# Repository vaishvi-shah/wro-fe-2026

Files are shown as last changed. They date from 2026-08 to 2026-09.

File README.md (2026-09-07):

# Hello! We are Team ElectroCute

<table align="center">
  <tr>
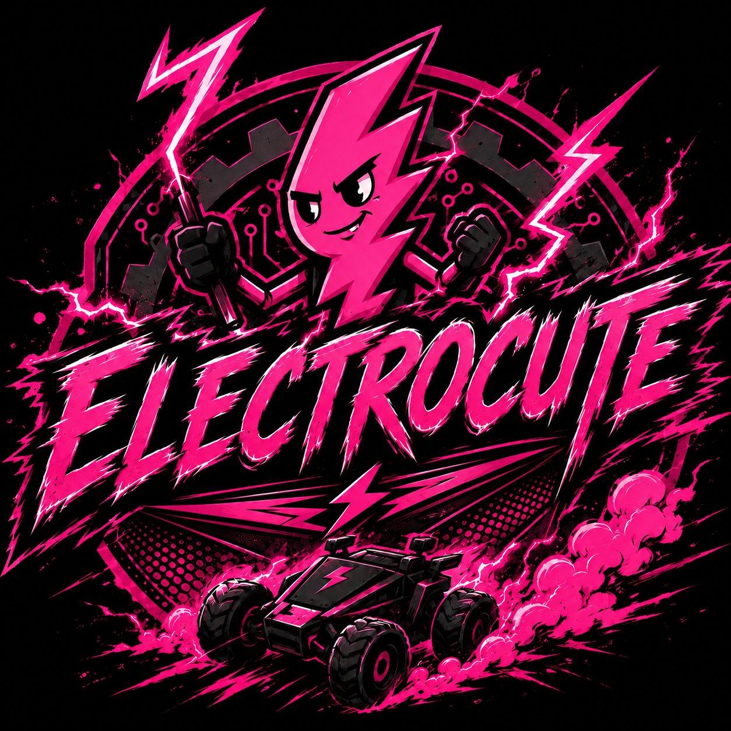
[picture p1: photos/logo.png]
    <td align="center"></td>
  </tr>
  <tr>
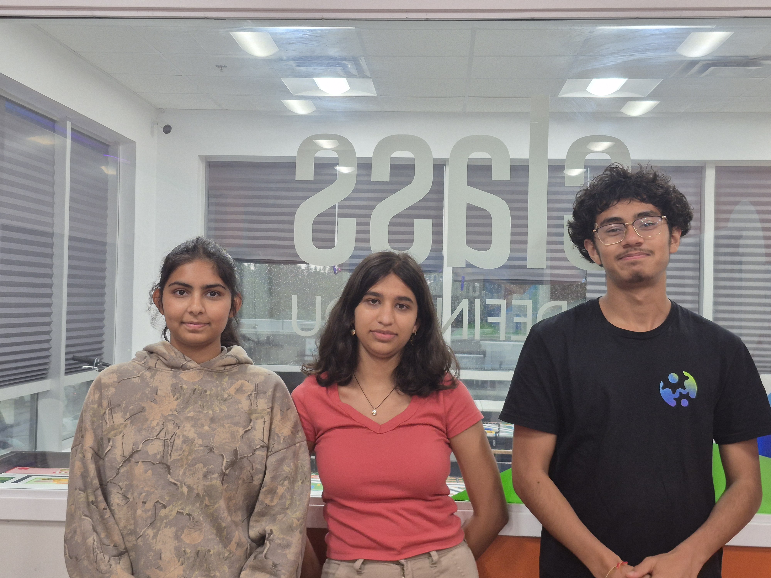
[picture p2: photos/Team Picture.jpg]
    <td align="center"></td>
  </tr>
</table>

We are a team of high school students from Whitby, Ontario, Canada participating in the **World Robot Olympiad (WRO) Future Engineers 2026** category.

<table align="center">
  <tr>
    <td align="center"><strong>Member</strong></td>
    <td align="center"><strong>Role</strong></td>
  </tr>
  <tr>
    <td align="center">Vaishvi Shah</td>
    <td align="center">Software &amp; Logic</td>
  </tr>
  <tr>
    <td align="center">Avani Devalankar</td>
    <td align="center">3D Design &amp; Hardware</td>
  </tr>
  <tr>
    <td align="center">Jaitra Bhatt</td>
    <td align="center">Documentation</td>
  </tr>
</table>

# Overview

The primary objective was to build an autonomous robot capable of navigating a closed course with obstacles and parallel parking itself at the end.

We chose this project because we wanted a challenging experience during high school where we could apply our Python skills while developing new skills in electronics, CAD, and 3D printing. We also drew inspiration from top teams that participated in WRO Future Engineers over the past two years by studying their [GitHub repositories](https://github.com/World-Robot-Olympiad-Association).

Our main objective was to create a dependable and effective system while showcasing our engineering, problem-solving, and teamwork skills. The project also gave us an opportunity to expand our knowledge and develop new skills throughout the process of building our robot.

We approached the development through several stages, beginning with idea generation and research, followed by designing, building, testing, and refining our system. We also kept thorough records of our work to make it easier to share information, track changes, and maintain a consistent workflow throughout the project.

### Summary Video

<a href="https://www.youtube.com/watch?v=VKRCWfLhV6I">
  Watch video
</a>

Click above to watch our video!

### Open Challenge Videos

https://github.com/user-attachments/assets/b752e2d7-2efb-4881-ae9d-5aae1f4fcaa4

### Obstacle Video

https://github.com/user-attachments/assets/9520dfca-cd9e-48ff-8d53-4761ecfdaf9c

## Table of Content

- [Overview](#overview)
  - [Summary Video](#summary-video)
  - [Open Challenge Videos](#open-challenge-videos)
  - [Obstacle Video](#obstacle-video)
  - [Meet The Robot](#meet-the-robot)
    - [Preliminary Work](#preliminary-work)
- [Introduction](#introduction)
- [Mobility & Mechanical Design](#mobility--mechanical-design)
  - [First Iteration - LEGO Chassis](#first-iteration--lego-chassis)
  - [Second Iteration - 3D-Printed Chassis](#second-iteration--3d-printed-chassis)
    - [Chassis Design](#chassis-design)
    - [Issues Identified](#issues-identified)
  - [Third Iteration - Physical Fit](#third-iteration--physical-fit)
    - [Chassis & Motor Fit](#chassis--motor-fit)
    - [Chassis & Weight Distribution](#chassis--weight-distribution)
    - [Mounting & Fastening](#mounting--fastening)
    - [Accessibility & Wiring](#accessibility--wiring)
    - [Battery Placement](#battery-placement)
    - [Rear Wheel Bearings](#rear-wheel-bearings)
    - [Screw Usage](#screw-usage)
- [Parts Selection & Reasoning](#parts-selection--reasoning)
  - [Drive System](#drive-system)
    - [Motor Selection](#motor-selection)
      - [Motor 1: JGA25-371 620 RPM DC Motor](#motor-1-jga25-371-620-rpm-dc-motor)
        - [Motor 1 Specifications](#motor-1-specifications)
      - [Motor 2: Lower-RPM JGA25-371 Variant](#motor-2-lower-rpm-jga25-371-variant)
    - [Motor Torque and Acceleration Calculations](#motor-torque-and-acceleration-calculations)
      - [Parameters](#parameters)
      - [Summary](#summary)
      - [Motor Final Decision](#motor-final-decision)
    - [Steering, Servo & Differential Design](#steering-servo--differential-design)
      - [WLToys 144001](#wltoys-144001)
      - [Ackermann Steering](#ackermann-steering)
      - [Servo: MG90S Servo](#servo-mg90s-servo)
        - [Servo Specifications](#servo-specifications)
  - [Power & Sensor Architecture](#power--sensor-architecture)
    - [Component Placement](#component-placement)
    - [Microcontroller Selection & Development](#microcontroller-selection--development)
      - [Iteration 1: micro:bit](#iteration-1-microbit)
      - [Raspberry Pi Pico 2 W](#raspberry-pi-pico-2-w)
    - [Raspberry Pi 5](#raspberry-pi-5)
      - [MPU6050](#mpu6050)
      - [BNO055](#bno055)
      - [IMU Comparison Table](#imu-comparison-table)
      - [IMU Final Decision](#imu-final-decision)
  - [Motor Driver Iterations](#motor-driver-iterations)
    - [Iteration 1 — DRV8871](#iteration-1--drv8871)
    - [Iteration 2 — L298N](#iteration-2--l298n)
    - [Motor Driver Comparison Table](#motor-driver-comparison-table)
    - [Motor Driver Final Decision](#motor-driver-final-decision)
  - [Camera: OV5647 Wide-Angle Camera](#camera-ov5647-wide-angle-camera)
  - [Parking: TOF Sensor vs. Motor Encoder](#parking-tof-sensor-vs-motor-encoder)
    - [Parking Sensor Comparison Table](#parking-sensor-comparison-table)
    - [Parking Sensor Final Decision](#parking-sensor-final-decision)
  - [Control, Display & Support System](#control-display--support-system)
- [Final Circuit Architecture](#final-circuit-architecture)
  - [Main Battery: 12V Li-ion Pack](#main-battery-12v-li-ion-pack)
  - [Steering Servo: MG90S vs. SG90](#steering-servo-mg90s-vs-sg90)
  - [Chassis Material: 3D-Printed PLA-CF](#chassis-material-3d-printed-pla-cf)
  - [Wheels: LEGO Wheels and Tires](#wheels-lego-wheels-and-tires)
- [Power System Architecture](#power-system-architecture)
  - [Two Board Architecture](#two-board-architecture)
    - [Why Two Boards?](#why-two-boards)
    - [Power Distribution](#power-distribution)
  - [Power Distribution Diagram: Nominal Values](#power-distribution-diagram-nominal-values)
  - [Nominal Current Draw for Each Part](#nominal-current-draw-for-each-part)
  - [Power Budget](#power-budget)
    - [5 V Power Requirement](#5-v-power-requirement)
    - [Motor Power](#motor-power)
    - [Total System Requirement](#total-system-requirement)
  - [Why This Matters](#why-this-matters)
- [Programming Logic](#programming-logic)
  - [Open Challenge Logic](#open-challenge-logic)
    - [1. Get Sensor Inputs](#1-get-sensor-inputs)
    - [2. Calculate Steering](#2-calculate-steering)
    - [3. Clamp Steering](#3-clamp-steering)
    - [4. Check for Bottom Lines](#4-check-for-bottom-lines)
  - [Obstacle Challenge Code](#obstacle-challenge-code)
    - [Iteration 1 — Initial Obstacle Avoidance](#iteration-1--initial-obstacle-avoidance)
      - [Iteration 1 Step 1: Detect an Obstacle](#iteration-1-step-1-detect-an-obstacle)
      - [Iteration 1 Step 2: Select the Obstacle to React To](#iteration-1-step-2-select-the-obstacle-to-react-to)
      - [Iteration 1 Step 3: Determine the Passing Side](#iteration-1-step-3-determine-the-passing-side)
      - [Iteration 1 Step 4: Find the Gap to Steer Through](#iteration-1-step-4-find-the-gap-to-steer-through)
      - [Iteration 1 Step 5: Steer Toward the Gap](#iteration-1-step-5-steer-toward-the-gap)
      - [Iteration 1 Step 6: Safety Check](#iteration-1-step-6-safety-check)
      - [Iteration 1 Step 7: Check if the Obstacle Was Cleared](#iteration-1-step-7-check-if-the-obstacle-was-cleared)
    - [Iteration 2 — Improved Obstacle Avoidance](#iteration-2--improved-obstacle-avoidance)
      - [Iteration 2 Step 1: Detect an Obstacle](#iteration-2-step-1-detect-an-obstacle)
      - [Iteration 2 Step 2: Select the Closest Obstacle](#iteration-2-step-2-select-the-closest-obstacle)
      - [Iteration 2 Step 3: Determine the Passing Side](#iteration-2-step-3-determine-the-passing-side)
      - [Iteration 2 Step 4: Improve the Gap Calculation](#iteration-2-step-4-improve-the-gap-calculation)
      - [Iteration 2 Step 5: Steer Toward the Gap](#iteration-2-step-5-steer-toward-the-gap)
      - [Iteration 2 Step 6: Safety Check — Obstacle Too Close](#iteration-2-step-6-safety-check--obstacle-too-close)
      - [Iteration 2 Step 7: Check if the Obstacle Is Cleared](#iteration-2-step-7-check-if-the-obstacle-is-cleared)
    - [Iteration Comparison](#iteration-comparison)
    - [Parking](#parking)
      - [`OUT_PARKING`](#out_parking)
      - [`IN_PARKING`](#in_parking)
    - [Running the Program](#running-the-program)
    - [Running the Program on Startup](#running-the-program-on-startup)
    - [CAD and Wiring Files](#cad-and-wiring-files)
  - [Step-by-Step Assembly Guide](#step-by-step-assembly-guide)
    - [1. Print the Chassis](#1-print-the-chassis)
    - [2. Assemble the Drivetrain](#2-assemble-the-drivetrain)
    - [3. Assemble the Steering](#3-assemble-the-steering)
    - [4. Mount Layer 1 Components](#4-mount-layer-1-components)
      - [Camera Position](#camera-position)
    - [5. Mount Layer 2 Components](#5-mount-layer-2-components)
    - [6. Wire the Power System](#6-wire-the-power-system)
      - [Wiring Recommendations](#wiring-recommendations)
    - [7. Wire Control Signals](#7-wire-control-signals)
    - [8. Attach the Front Bumper](#8-attach-the-front-bumper)
    - [9. Calibrate Before Every Run](#9-calibrate-before-every-run)
    - [10. Bench Test Before Full Track Runs](#10-bench-test-before-full-track-runs)
## Meet The Robot

<table align="center">
  <tr>
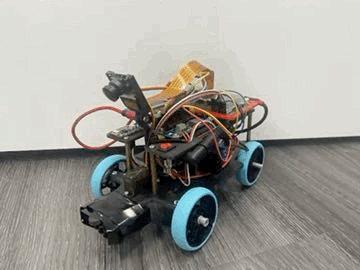
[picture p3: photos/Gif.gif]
    <td align="center"><strong>GIF</strong><br></td>
  </tr>
</table>
Meet Batmobile, our autonomous car designed and 3D-printed for WRO Future Engineers 2026. The brain of the robot is a Raspberry Pi 5, which processes the camera feed using OpenCV and handles navigation, obstacle detection, and sensor logic. A Raspberry Pi Pico communicates with the Pi through a USB serial connection and controls the DC motor and steering servo.

Batmobile uses a camera, IMU, and encoder sensor to navigate the field. The camera provides visual information for navigation and obstacle detection, the IMU helps maintain a straight heading and execute accurate turns, and the encoder sensor assists with precise parking. Together, these systems allow Batmobile to independently perceive its surroundings, make decisions, and navigate the competition field.

### Preliminary Work

We found the public WRO repositories especially useful when getting started. Being able to look at documentation from previous teams gave us a reference for how to approach the competition without having to figure everything out from scratch. We’ve tried to do the same with our documentation by making it practical and detailed enough that a future team can use it as a starting point for their own robot.

# Introduction

# Mobility & Mechanical Design

The chassis is built in a layered structure so that mounting space could be divided deliberately, with the first layer holding the heavier components and a second, elevated layer used to mount the electronics. This final version did not happen immediately; we went through many iterations to make it work.

## First Iteration  LEGO Chassis

**Starting Design**

Our first chassis was constructed using LEGO Technic pieces to create a basic structure for initial testing. A LEGO differential was incorporated into the drivetrain system to transfer power to the wheels while allowing them to rotate at different speeds during turns.

**Issues Identified**

During testing, we encountered several mechanical problems. The wheels frequently came off the chassis during movement and turning. The steering system also had a limited Ackermann steering angle, which made it difficult for the robot to perform tight turns. This was especially problematic during parking, where greater steering angles were needed to maneuver within the available space. Additionally, the differential would come off the axle during operation, affecting the reliability of the drivetrain.

<table align="center">
  <tr>
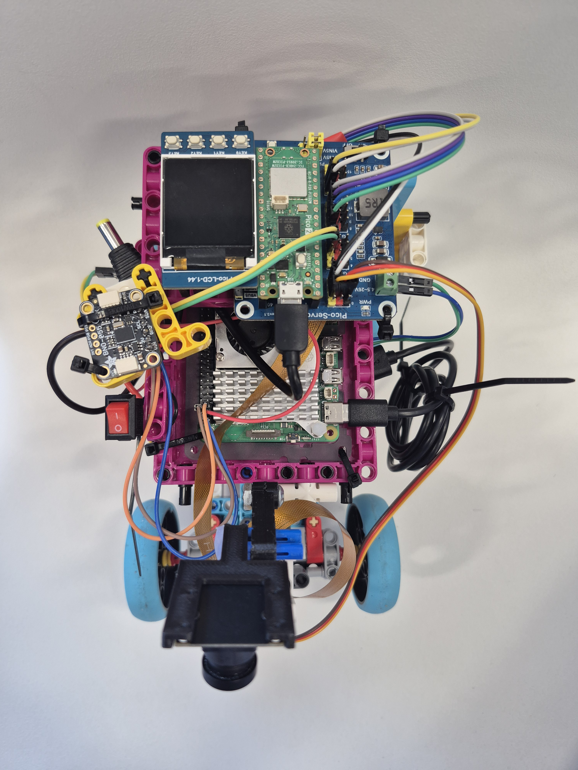
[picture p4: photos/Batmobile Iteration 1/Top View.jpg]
    <td></td>
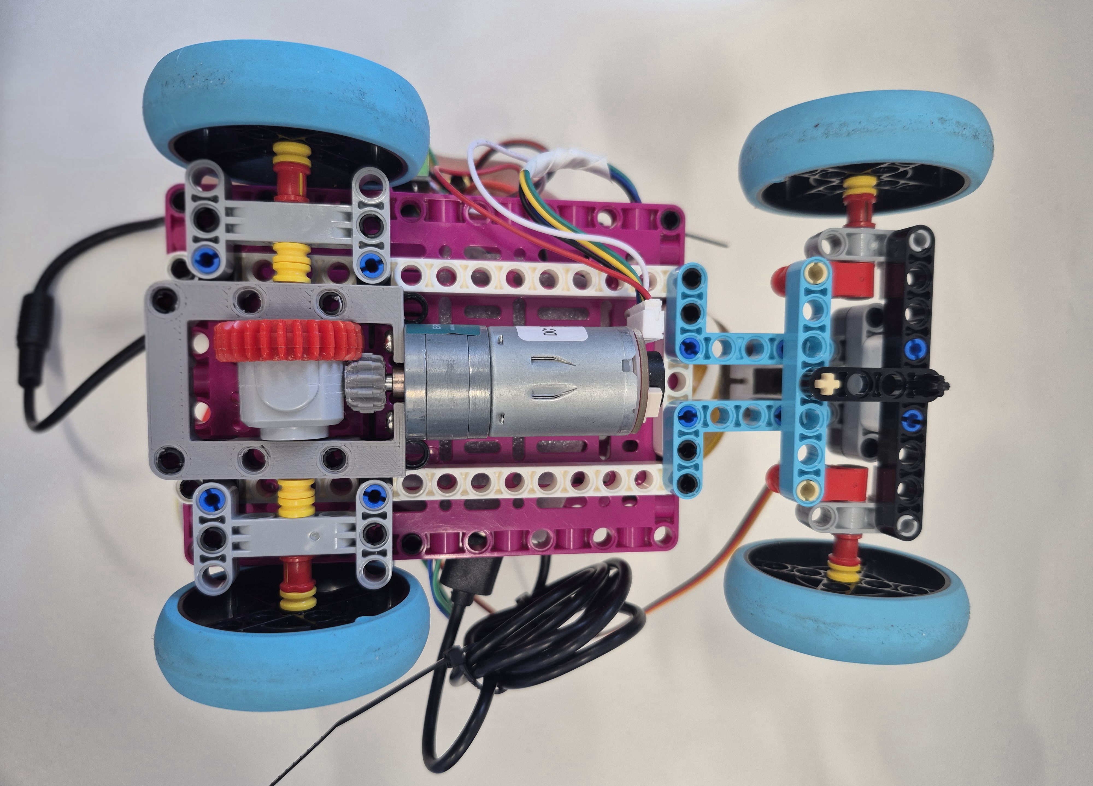
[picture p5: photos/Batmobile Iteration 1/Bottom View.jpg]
    <td></td>
  </tr>
  <tr>
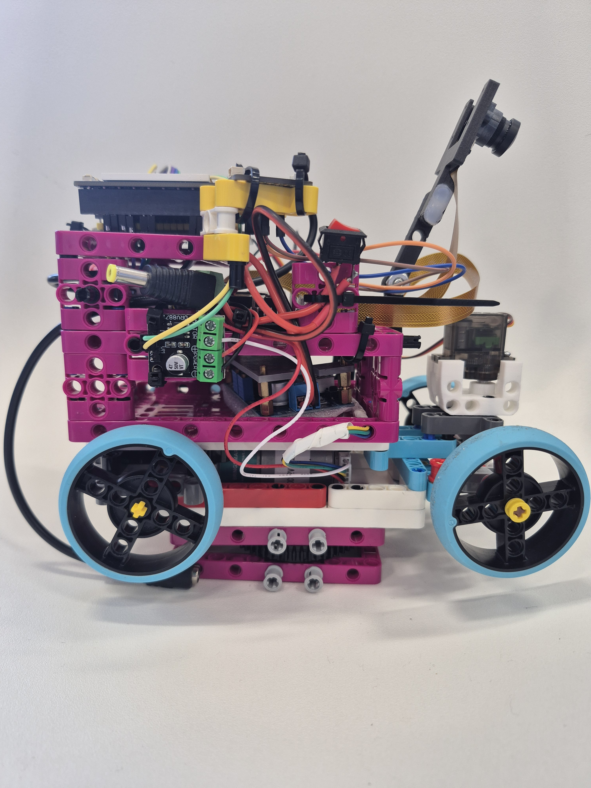
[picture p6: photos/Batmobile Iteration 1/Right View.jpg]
    <td></td>
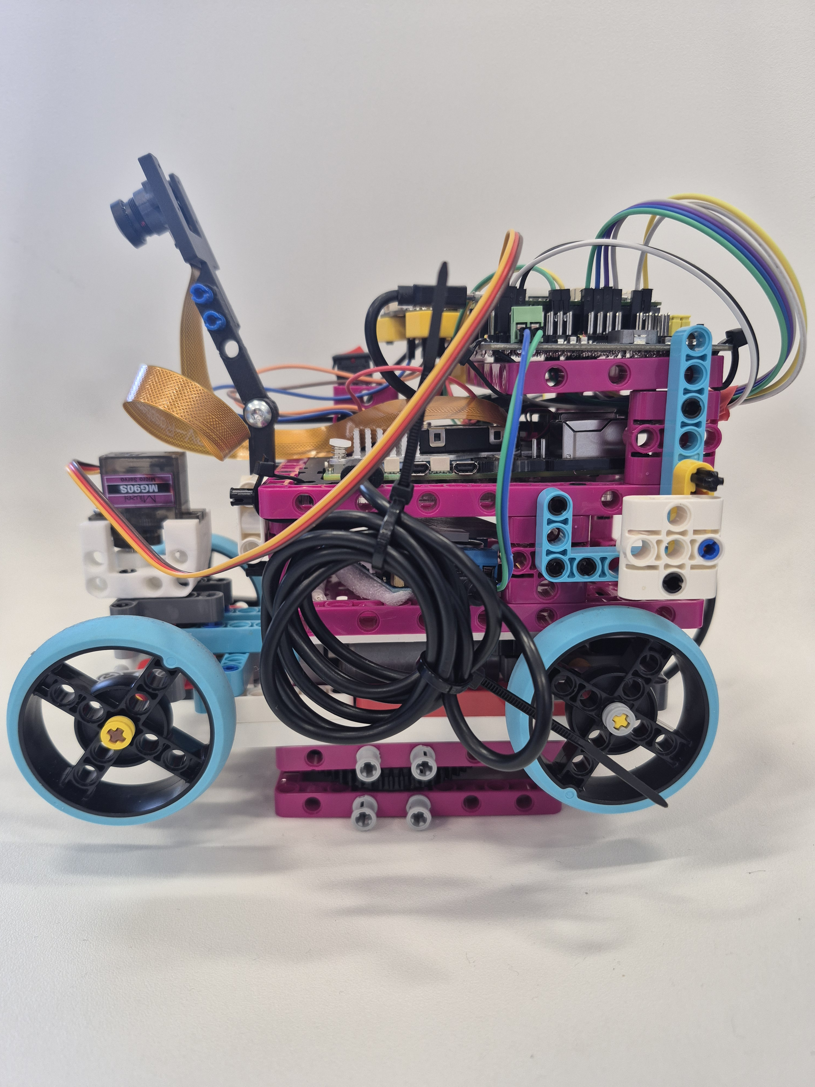
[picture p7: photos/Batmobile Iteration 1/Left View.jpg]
    <td></td>
  </tr>
</table>

## Second Iteration  3D-Printed Chassis

### Chassis Design

We replaced the original LEGO chassis with a custom 3D-printed chassis designed specifically around our robot’s components. The chassis was divided into two separate layers to organize the mechanical and electronic components:

- Layer 1: Battery, motor driver, servo, and Ackermann steering system.
- Layer 2: Raspberry Pi 5, Raspberry Pi Pico 2, and IMU.

This two-layer structure provided dedicated mounting areas, improved component organization, and made the overall system easier to assemble and maintain.

### Issues Identified

During testing, we found that placing the battery toward the rear of the chassis caused an uneven weight distribution. This shifted the centre of mass toward the rear, reducing the normal force acting on the front wheels.

With less weight on the front wheels, the available front-wheel traction decreased, particularly during faster movement and sharp turns. At higher speeds, the front wheels would lose traction and lift slightly, which reduced steering effectiveness and made the robot less stable and predictable while turning.

<table align="center">
  <tr>
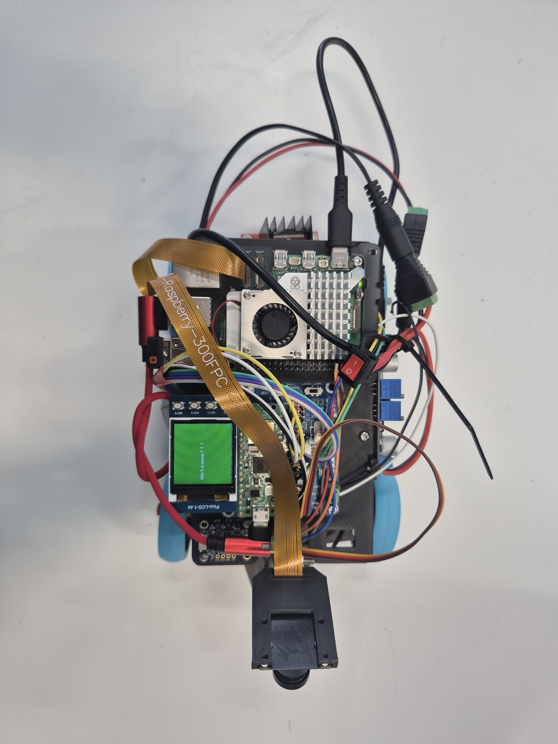
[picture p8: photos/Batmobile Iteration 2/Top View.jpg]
    <td></td>
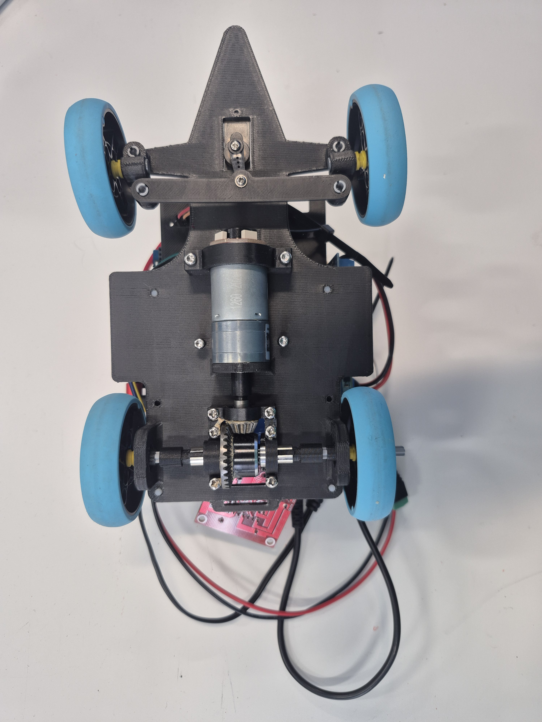
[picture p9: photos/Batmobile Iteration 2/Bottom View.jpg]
    <td></td>
  </tr>
  <tr>
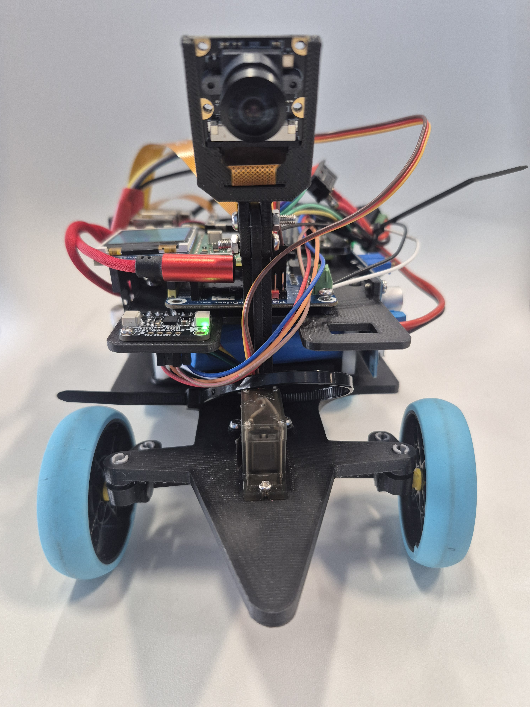
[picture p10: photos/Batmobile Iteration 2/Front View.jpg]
    <td></td>
    <td></td>
  </tr>
</table>

## Third Iteration  Physical Fit

<table align="center">
  <tr>
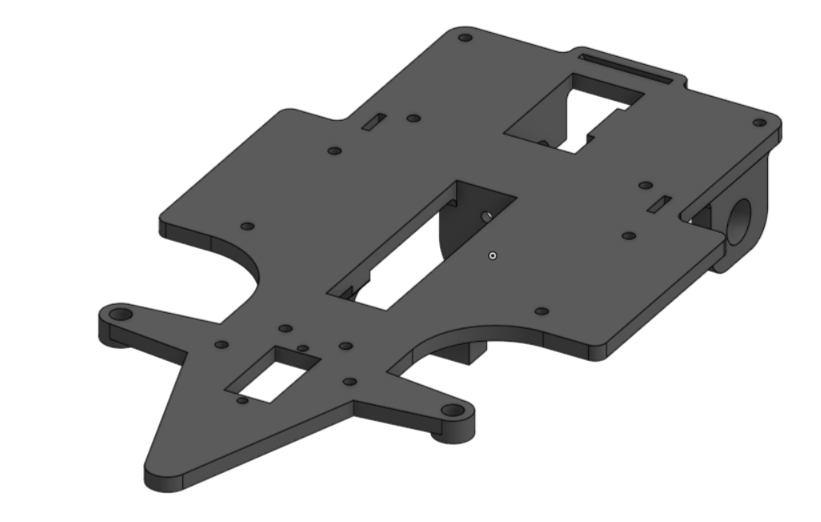
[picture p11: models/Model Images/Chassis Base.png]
    <td align="center"><strong>Chassis Base</strong><br></td>
  </tr>
</table>

### Chassis & Motor Fit

The chassis was extended after measuring the physical DC motor and discovering that it was longer than the original CAD model. An access hole was added to allow easier access to the motor mounting screws during assembly and maintenance. Finally, the motor clamp geometry was adjusted to improve the fit, including reducing the clamp diameter by 0.25 mm for a tighter connection.

### Chassis & Weight Distribution

The front of the chassis was extended to create more space for parking and make the robot easier to maneuver. We also moved the battery closer to the centre of the chassis to balance the weight more evenly and improve stability.

Additional space was made inside the chassis to fit the updated DC motor, which had different dimensions from the previous motor. We also replaced the previous motor driver with a new motor driver setup, so the layout of the internal components had to be adjusted to fit everything properly.

### Mounting & Fastening

The LEGO peg holes were increased by 0.1 mm after testing showed that the original holes were slightly too small. We also added dedicated mounting holes for the servo so it could be securely attached to the chassis.

Before finalizing the design, we test-fitted each clamp with its corresponding physical component. This helped us check that the dimensions were correct and catch any fitting issues before final assembly.

<table align="center">
  <tr>
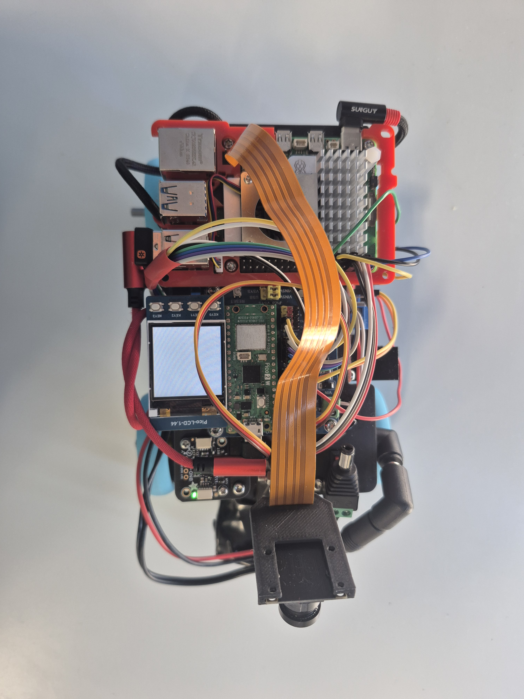
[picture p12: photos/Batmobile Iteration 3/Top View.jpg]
    <td></td>
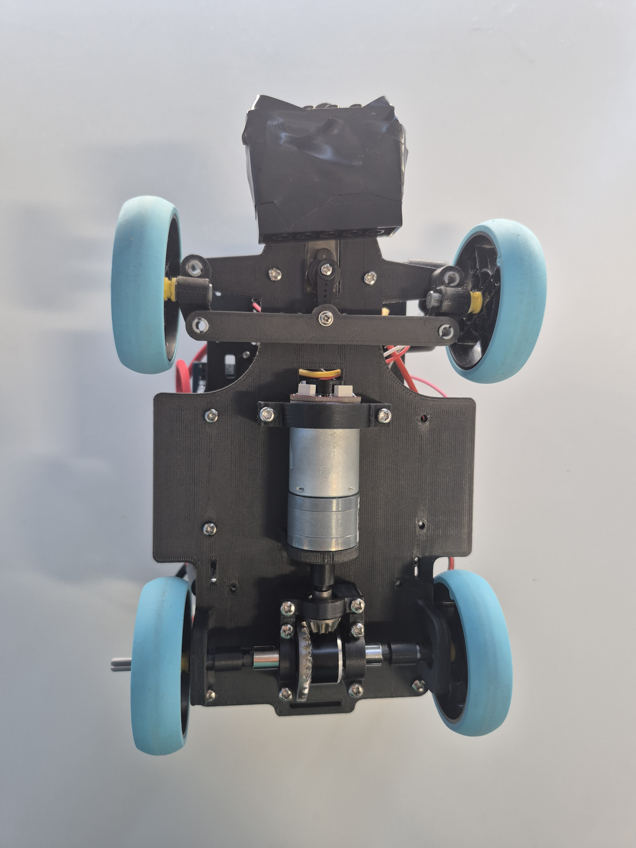
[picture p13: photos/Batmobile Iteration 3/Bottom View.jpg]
    <td></td>
  </tr>
  <tr>
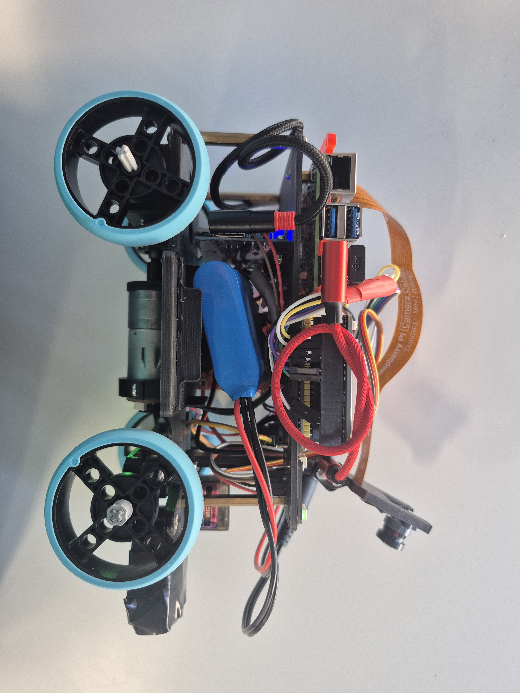
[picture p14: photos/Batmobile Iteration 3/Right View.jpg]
    <td></td>
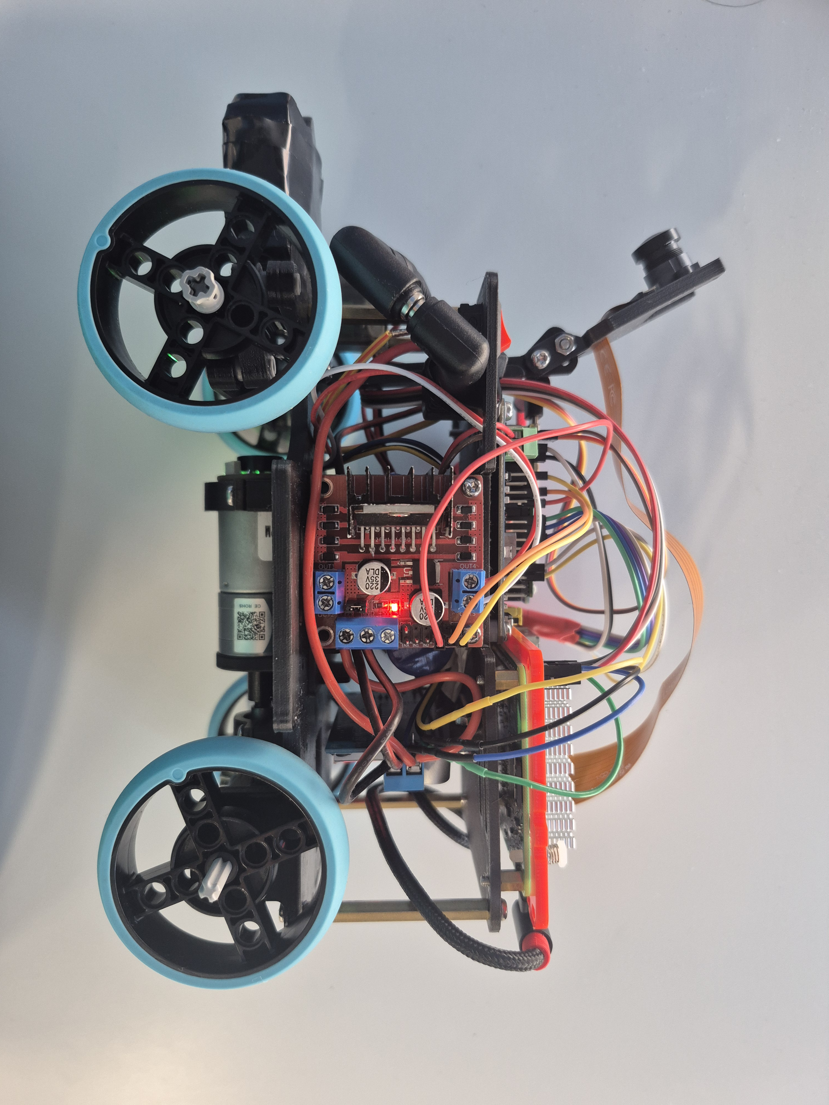
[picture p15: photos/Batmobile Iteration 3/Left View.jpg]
    <td></td>
  </tr>
</table>

### Accessibility & Wiring

The chassis was designed to keep the wiring and electrical components accessible. This allowed us to easily reach the connections during testing, troubleshooting, and repairs without having to completely disassemble the robot.

### Battery Placement

Initially, the battery was positioned toward the rear of the robot, but this caused uneven weight distribution and shifted the centre of mass backward.

To solve this, we moved the battery toward the centre of the chassis, which distributed the weight more evenly and improved stability and traction during turns.

### Rear Wheel Bearings

We added bearings to the rear wheel axles to reduce friction between the axles and the chassis. This allowed the rear wheels to rotate more smoothly and freely, reducing mechanical resistance and improving the robot's overall movement and consistency.

### Screw Usage

We switched to M3 screws throughout the assembly, replacing the larger fasteners used in earlier versions. This helped reduce the overall weight of the robot while still providing enough strength to securely hold the chassis.

Using one standard screw size also made assembly and part sourcing simpler by reducing the number of different fasteners required.## Drive System

### Motor Selection

### Motor 1: JGA25-371 620 RPM DC Motor

<table>
  <tr>
    <td align="center"><strong></strong><br></td>
  </tr>
</table> 

### Specifications

| Specification | Value |
|---|---|
| Reduction Ratio | 9.6:1 |
| Rated Voltage | 12V |
| Speed | 477 RPM |
| Current | 60 mA |
| Torque | 0.22 kg·cm |
| Current | 0.3 A |

The WRO track is flat, so we did not need the extra stall torque provided by the lower-RPM motors to handle slopes. Instead, we chose the 620 RPM motor because its higher top speed allows the robot to move faster during the open sections of the track, helping us achieve faster lap times.

## Drive System

### Motor 2: Lower-RPM JGA25-371 Variant

<table>
  <tr>
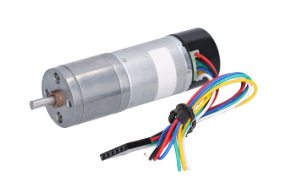
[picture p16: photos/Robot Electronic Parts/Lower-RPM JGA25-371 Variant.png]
    <td align="center"><strong></strong><br></td>
  </tr>
</table> 

| Specification | Lower-RPM JGA25-371 (~126–280 RPM) |
|---|---|
| Operating voltage | 6–24V (12V nominal) |
| Free-run speed at 12V | ~126–280 RPM depending on ratio |
| Stall torque at 12V | ~2.65–4.2 kg·cm depending on ratio |
| Free-run current at 12V | ~46 mA |
| Encoder | Integrated, ~12 counts/rev |
| Main advantage | Higher torque margin for acceleration and obstacle-course maneuvering |
| Main disadvantage | Lower top speed, resulting in slower lap times on the open/obstacle track |

At a 1:34 ratio, the motor runs at approximately 126 RPM at 12V with roughly 4.2 kg·cm of stall torque, while a 201 RPM version provides approximately 2.65 kg·cm of stall torque.

The higher gear reduction gives the robot more torque at the wheels, which improves acceleration and helps it overcome resistance. However, this also reduces the robot’s maximum speed. Since the WRO track is flat and has open sections where speed is important, we decided that the additional torque was not as useful as having a higher top speed.
## Motor Torque and Acceleration Calculations

These calculations evaluate whether our **695 g robot** can reach the target wheel speed of **150 RPM within 0.5 seconds**, using a **JGA25-371 motor** with **2.5:1 gearing**.

### Parameters

| Parameter | Symbol | Value |
|---|---|---:|
| Robot mass | `m` | 0.695 kg |
| Wheel diameter | `d` | 56 mm |
| Wheel radius | `r` | 0.028 m |
| Motor | — | JGA25-371, 620 RPM |
| Motor stall torque | `Tₛ` | 0.0833 N·m |
| Gear ratio | `R` | 2.5:1 |
| Target wheel speed | `vₜ` | 150 RPM |
| Acceleration time | `t` | 0.5 s |
| Combined efficiency | `η` | 0.90 |
| Rolling resistance coefficient | `Cᵣᵣ` | 0.03 |
| Target linear velocity | `v` | 0.440 m/s |
| Required acceleration | `a` | 0.880 m/s² |
| Acceleration torque at wheel | `Tₐcc` | 0.0171 N·m |
| Rolling resistance torque | `Tᵣᵣ` | 0.00573 N·m |
| Total required wheel torque | `Tᵥ` | 0.0228 N·m |
| Required motor torque | `Tₘ` | 0.0102 N·m |
| Available motor torque @ 375 RPM | `T_available` | ≈ 0.0329 N·m |

### Summary

With the robot mass updated to **695 g**, the required motor torque to accelerate to **150 RPM in 0.5 seconds** is approximately **0.0102 N·m**.

At the corresponding motor speed of **375 RPM**, the JGA25-371 motor provides approximately **0.0329 N·m** of available torque.

Therefore, the motor provides **over 3× the calculated required torque**, giving the robot a sufficient torque margin for the target acceleration and speed.
### Final Decision

We chose the JGA25-371 620 RPM DC Motor because it provides a good balance of speed, torque, and size for our robot. The motor also has an integrated encoder, which allows us to measure its rotation and use that feedback for more accurate speed control.

We paired it with the WLToys 144001 differential, which transfers power to the rear wheels while allowing the wheels to rotate at different speeds when turning. Overall, this setup gave us the speed and control we needed for the WRO track.

| Risk | Mitigation |
|---|---|
| The stall torque for the specific 620 RPM gear ratio is not published by the vendor, so the value is estimated by scaling down from documented lower-RPM variants in the same JGA25-371 family. | Encoder feedback allows the motor's actual RPM to be monitored under load. A significant RPM drop without a corresponding increase in the drive command can indicate that the motor is approaching its available torque limit. This allows a potential torque shortfall to be identified during testing before competition. |

### Steering, Servo & Differential Design

### WLToys 144001

<table>
  <tr>
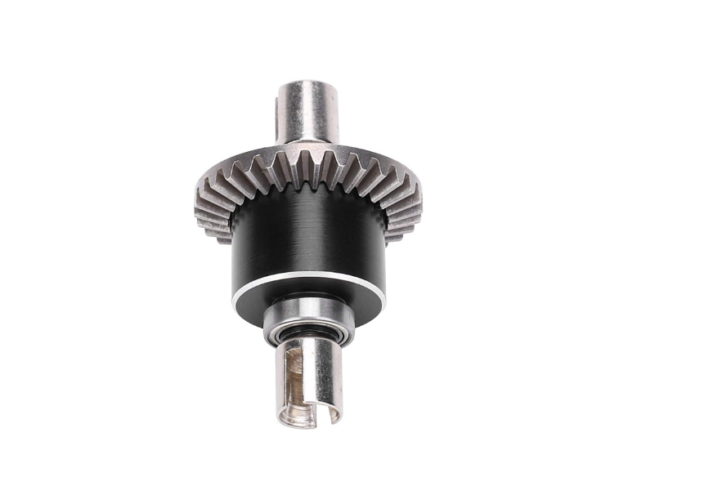
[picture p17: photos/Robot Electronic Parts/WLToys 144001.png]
    <td align="center"><strong></strong><br></td>
  </tr>
</table> 

Our first drivetrain used a LEGO differential to drive the rear wheels, allowing the wheels to rotate at different speeds during turns and reducing wheel scrub. However, the differential axle repeatedly came loose during sharper turns.

To improve reliability and performance, we replaced the LEGO differential with a WLToys 144001 differential, which has a 2.5:1 reduction ratio. This provided a stronger connection, smoother movement, and more consistent turning while eliminating the axle-loosening issue.

### Ackermann Steering

Our initial LEGO robot used Ackermann steering, but when we switched to the custom chassis, the original steering geometry caused the robot to slip whenever it moved. We adjusted the Ackermann steering angle to better suit the new chassis geometry, reducing wheel slip and improving steering stability.

The new linkage also made better use of the servo’s approximately 50°–130° operating range, rather than having its movement restricted by the previous LEGO chassis geometry.

| Position | Angle |
|---|---|
| Center | 82° |
| Full Left | Center - 45° |
| Full Right | Center + 45° |

This was necessary because the inside wheel travels along a smaller circle, while the outside wheel travels along a larger circle. By turning the wheels at different angles, the robot can follow the correct path through a corner and turn more smoothly without the tires dragging across the ground.

| Risk | Mitigation |
|---|---|
| The steering range was originally limited to 0°–90° because of a servo bug discovered during Iteration 1. | We traced and corrected the bug, then tested the servo against the physical Ackermann linkage to determine its actual mechanical limits. |
| Using a steering range beyond the mechanical limits could cause the linkage to bind or damage the components. | We verified a safe 50°–130° range through physical testing and permanently adopted it as the steering limit. Every steering formula in our software clamps its output to this range. |

### Servo: MG90S Servo

<table>
  <tr>
    <td align="center"><strong></strong><br>
</td>
  </tr>
</table> 

### Specifications

| Specification | Value |
|---|---|
| Rated Torque | 1.1 kgf/cm |
| Speed | 0.15 sec/60° |
| Voltage | 5V |
| Gearing | Metal |
| Type | Digital |

We chose the servo because its compact size and PWM control made it well suited for steering. Its torque was enough to move the front wheels reliably and respond quickly to steering commands. It is also commonly used in robotics, so finding documentation and compatible mounting hardware was straightforward.

After considering several steering options, we selected Ackermann steering geometry because it reduces tire slip and improves turning accuracy. The inside and outside front wheels turn at different angles, allowing each wheel to follow its own turning path. Our steering linkage is arranged so that the projected lines of the front wheels meet near the rear axle, creating the desired Ackermann geometry.

# Power & Sensor Architecture

## Component Placement

<table>
  <tr>
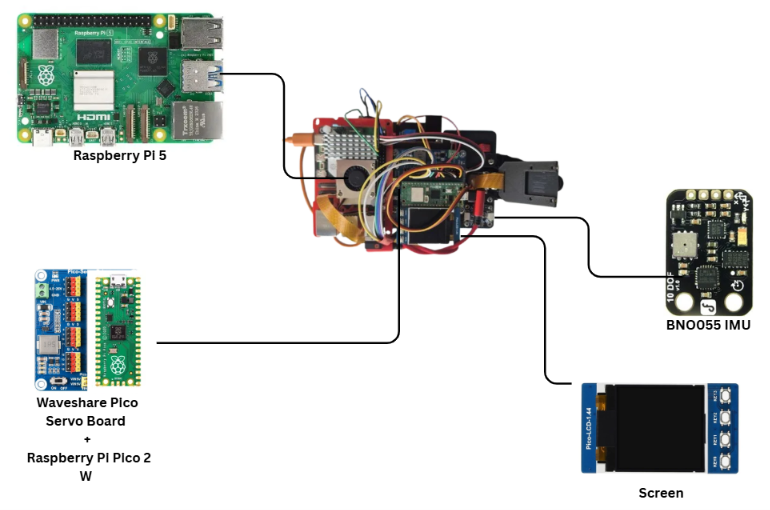
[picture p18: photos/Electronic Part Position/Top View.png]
    <td></td>
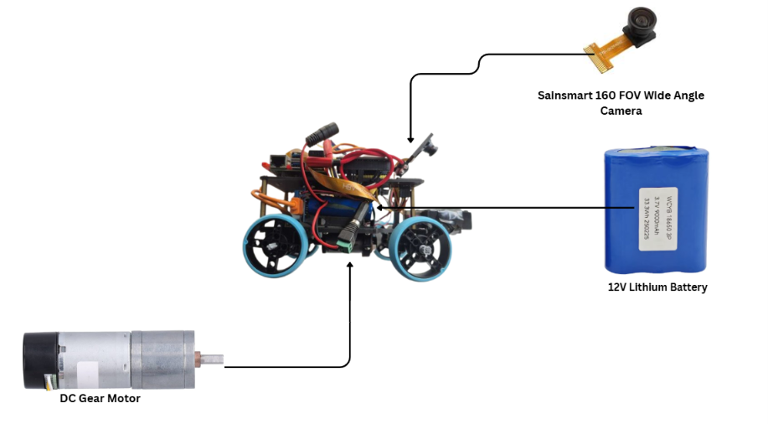
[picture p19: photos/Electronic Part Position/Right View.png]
    <td></td>
  </tr>
  <tr>
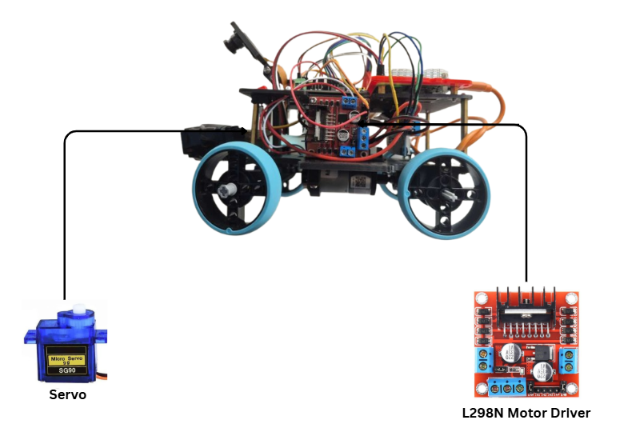
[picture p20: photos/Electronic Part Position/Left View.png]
    <td></td>
    <td><img src="https://github.com/vaishvi-shah/wro-fe-2026/blob/main/photos/Electronic%20Part%20Position/Back%20View.png" " width="400" height="600" /></td>
  </tr>
</table> 

## Microcontroller Selection & Development

The microcontroller handles the robot's low-level control, including the motor, steering servo, and IMU, while communicating with the Raspberry Pi 5 for higher-level processing and decision-making.

### Iteration 1: micro:bit

<table>
  <tr>
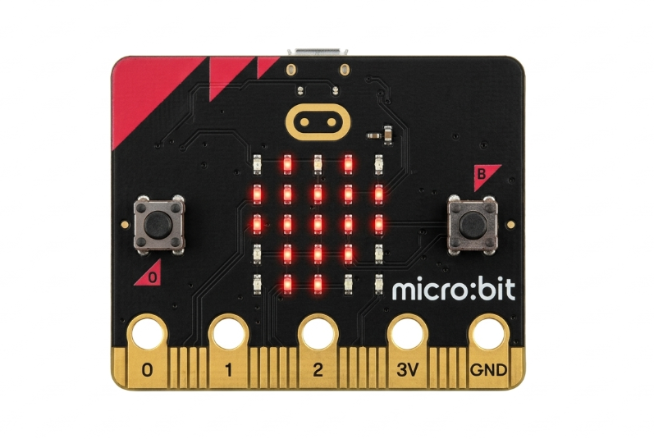
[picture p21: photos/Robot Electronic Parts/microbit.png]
    <td align="center"><strong></strong><br></td>
  </tr>
</table> 

The micro:bit is a compact board based on the Nordic nRF52833. It includes an accelerometer, magnetometer, Bluetooth, LED matrix, and two buttons.

- Advantage: Easy to program and quick to test.
- Disadvantage: Limited motor and servo control.
- Testing: The Raspberry Pi connection was unreliable.

### Raspberry Pi Pico 2 W

<table>
  <tr>
    <td align="center"><strong></strong><br>
</td>
  </tr>
</table> 

The Raspberry Pi Pico 2 W uses the RP2350 and has Wi-Fi, Bluetooth, and 26 GPIO pins. It does not have built-in sensors, but it can connect to many sensors and devices.

- Main advantage: It has many GPIO pins and supports PWM, I²C, SPI, and UART.
- Main disadvantage: It required more setup and testing to get all of our hardware communicating correctly.
- Final solution: After testing and configuring the Pico 2 W, we were able to reliably control the motor and servo while communicating with the Raspberry Pi 5.

## Raspberry Pi 5

<table>
  <tr>
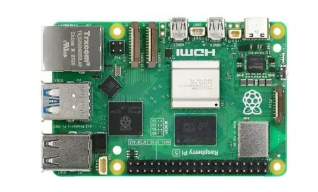
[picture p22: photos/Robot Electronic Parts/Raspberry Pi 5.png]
    <td align="center"><strong></strong><br></td>
  </tr>
</table> 

No second board was tested against the Raspberry Pi 5. It was selected at the beginning of the design because the robot's navigation system requires real-time processing of camera data for lane, wall, and pillar detection.

| Specification | Raspberry Pi 5 (4GB) |
|---|---|
| CPU | Broadcom BCM2712, quad-core Cortex-A76 @ 2.4 GHz |
| RAM | 4GB LPDDR4X |
| Camera interface | MIPI CSI-2 |
| Connectivity | Gigabit Ethernet, Wi-Fi, Bluetooth, USB 3.0 |
| Cooling | Active cooling required under sustained load; heatsink and fan used |
| Main advantage | Sufficient CPU headroom for real-time computer vision |
| Main disadvantage | Highest power draw and cooling requirement of the computing boards |

The Raspberry Pi 5 was chosen because the robot needs to process live camera video to detect lanes, walls, and pillars.

- Main advantage: It has enough processing power to handle real-time camera and computer vision tasks.
- Main disadvantage: The Raspberry Pi 5 has higher power consumption, which puts more demand on the robot's battery.
- Cooling: Active cooling was added to prevent overheating during long periods of use.

#### MPU6050

<table>
  <tr>
    <td align="center"><strong></strong><br>
</td>
  </tr>
</table> 

The MPU6050 is a 6-DOF IMU containing a 3-axis accelerometer and 3-axis gyroscope, but it does not include a magnetometer. It provides raw accelerometer and gyroscope measurements rather than directly providing a fully processed orientation estimate. Its main advantages are its low cost, small size, and high output rate of up to 1000 Hz, which would provide more than enough measurements for a fast steering control loop.

#### BNO055

<table>
  <tr>
    <td align="center"><strong></strong><br>
</td>
  </tr>
</table> 

The BNO055 is a 9-DOF IMU containing a 3-axis accelerometer, 3-axis gyroscope, and 3-axis magnetometer which can provide ready-to-use orientation data processed by the inbuilt 32-bit Cortex-M0+ microprocessor. The main trade-off is that the BNO055 is more expensive and has a lower output rate than the MPU6050.

### Comparison Table

| Specification | MPU6050 | BNO055 |
|---|---|---|
| Degrees of freedom | 6-DOF | 9-DOF |
| Accelerometer | 3-axis | 3-axis |
| Gyroscope | 3-axis | 3-axis |
| Magnetometer | No | 3-axis |
| Sensor-fusion processor | Host microcontroller required | 32-bit Cortex-M0+ |
| Maximum output rate | Up to 1000 Hz | — |
| Fusion output rate | — | Approximately 100 Hz |
| Orientation processing | Host microcontroller required | Integrated sensor fusion |
| Current in 9-DOF fusion at 100 Hz | — | Approximately 12.3 mA |
| Orientation output | — | Euler angles and quaternions |
| Interfaces | — | I²C, UART |
| Main advantage | Low cost and high output rate | Integrated sensor fusion and improved heading reference |
| Main disadvantage | Yaw drift and additional sensor-fusion software | Higher cost and lower output rate |

### Final Decision

The BNO055 was selected because reliable heading information was more important for our robot than the MPU6050's lower cost and higher output rate. Our main reason for using an IMU was to maintain the robot's heading when the camera could not provide reliable information, such as during blind spots and parking turns. This made stable yaw information especially important.

The BNO055's magnetometer provides a magnetic reference that helps reduce the effects of gyroscope drift, while its onboard sensor fusion handles much of the orientation processing for us. Although the BNO055 costs more and has a lower output rate, we accepted these trade-offs because it gave us simpler software and more reliable heading control.

# Motor Driver Iterations

### Iteration 1 — DRV8871

<table>
  <tr>
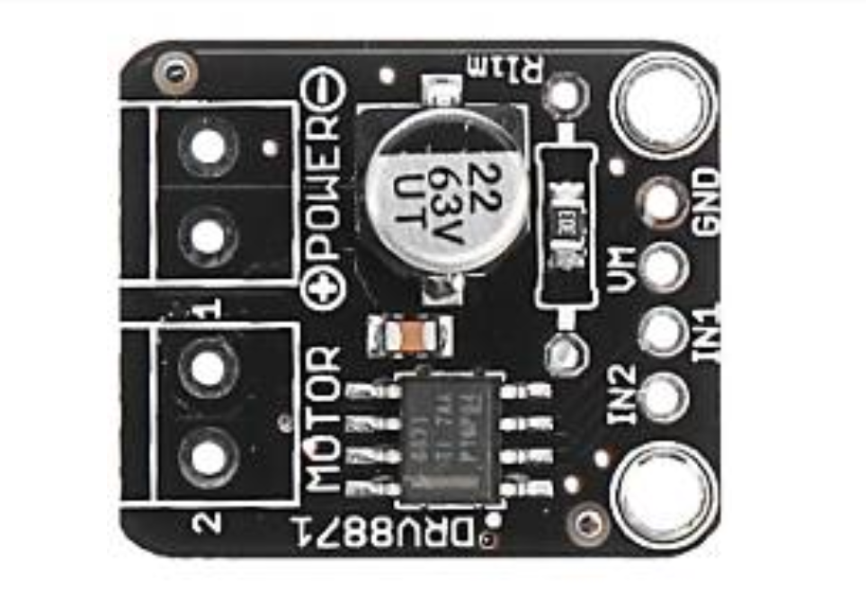
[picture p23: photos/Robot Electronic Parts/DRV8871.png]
    <td align="center"><strong></strong><br></td>
  </tr>
</table> 

We initially chose the DRV8871 because it was compact, efficient, and its single-channel design was sufficient for our one-motor drivetrain. During testing, we found that it could not handle the voltage and current conditions from our 12 V motor system and eventually burned out.

### Iteration 2 — L298N

<table>
  <tr>
    <td align="center"><strong></strong><br>
</td>
  </tr>
</table> 

We replaced the DRV8871 with an L298N. The L298N is a dual H-bridge, so the second motor channel is unused in our application. It is larger and has a voltage drop of approximately 1.5–2 V, meaning our motor receives around 10–10.5 V from the nominal 12 V battery. However, it handled our motor's operating conditions reliably during testing, so we selected it for the final robot.

### Comparison Table

| Specification | DRV8871 | L298N |
|---|---|---|
| Motor channels | 1 | 2 |
| Driver type | Single H-bridge | Dual H-bridge |
| Voltage drop | Low | Approximately 1.5–2 V |
| Motor voltage from 12 V battery | Up to motor supply voltage | Approximately 10–10.5 V |
| Thermal management | Integrated thermal protection | Heatsink / high thermal mass |
| Main advantage | Compact, efficient, and single-channel | Reliable under our tested conditions |
| Main disadvantage | Could not handle our tested 12 V system | Larger size and higher voltage loss |

### Final Decision

We selected the L298N as our final motor driver because it proved to be the most reliable option during testing. Although it is larger and has a higher voltage drop than the DRV8871, it was able to consistently handle the operating conditions of our 12 V motor system without overheating or failing. For our robot, reliability was more important than having a smaller and more efficient driver, so the L298N was the better choice for the final design.

# Camera: OV5647 Wide-Angle Camera

<table>
  <tr>
    <td align="center"><strong></strong><br>
</td>
  </tr>
</table> 

The camera listed in our BOM is the SainSmart Wide-Angle 5MP camera with the OV5647 sensor, which has a 160° field of view. The wide field of view allows the robot to see a larger area of the track and its surroundings compared to a narrower camera.

We use the camera for several parts of our navigation system, including lane, wall, and pillar detection. This allows one sensor to provide multiple types of information to the robot instead of requiring separate sensors for each feature.

The main advantage of using a wide-angle camera is its versatility and coverage. However, visual detection can become less reliable when parts of the track are blocked or when lighting and visibility make features harder to detect. Overall, the camera provides the range of visual information needed for our navigation system while keeping the sensor setup relatively simple.

# Parking: TOF Sensor vs. Motor Encoder

<table>
  <tr>
    <td align="center"><strong></strong><br>
</td>
  </tr>
</table> 

For parking, we considered two options: a VL53L0X Time-of-Flight (TOF) sensor and the motor encoder already built into our JGA25-371 motor. We compared them based on accuracy, reliability, hardware requirements, and how easily they could be integrated into our existing system.

The VL53L0X is a Time-of-Flight distance sensor that uses infrared light to measure the distance to an object. It can measure distances up to approximately 2 m and communicates with the Raspberry Pi through I²C. Its main advantage is that it measures direct distance so wheel slip does not directly affect the measured distance. However, using it requires resoldering the wires so the Raspberry Pi's I2C port can be used by both IMU and TOF sensors. Also, the VL53L0X's 25 degree field of view must be programmatically restricted or shifted  by configuring the Region of Interest (ROI) to a 4 x 4 SPAD range using the STMicroelectronics API.

The JGA25-371 motor has an integrated encoder that allows the Raspberry Pi Pico 2 W to monitor motor rotation and estimate how far the robot has travelled. Our selected 9.6:1 motor has a listed no-load speed of approximately 620 RPM, a rated-load speed of approximately 500 RPM, and approximately 0.9 kg·cm of rated-load torque. The main advantage is that the encoder reuses hardware already built into the drivetrain, so no additional distance sensor is needed. The trade-off is that it measures wheel movement rather than the robot’s actual position, meaning wheel slip and small differences in wheel diameter can introduce error.

### Comparison Table

| Feature | VL53L0X TOF Sensor | Motor Encoder |
|---|---|---|
| Measurement | Direct distance to an object | Estimated distance from wheel rotation |
| Communication | I²C | Encoder signal |
| Additional hardware | Requires a separate sensor | Already integrated into the motor |
| Affected by wheel slip | No | Yes |
| Main advantage | Measures the robot's actual distance from its surroundings | Reuses existing hardware and simplifies the system |
| Main disadvantage | Limited field of view and requires another I²C device | Distance can be affected by wheel slip and wheel diameter |
| Selected for parking | No | Yes |

### Final Decision

We selected the motor encoder for parking because the parking area provides a relatively controlled environment where repeatable wheel movement is sufficient for our parking sequence. Using the encoder also simplifies our sensor architecture by removing a dedicated distance sensor and reducing the number of devices using the I²C bus.

This allowed us to keep the BNO055 as the sole sensor connected to the Raspberry Pi's I²C port while using the existing motor encoder for the distance information needed during parking. Although the encoder can introduce some error from wheel slip, the simpler setup and reuse of existing hardware made it the better choice for our robot.

# Control, Display & Support System

The robot uses several supporting electronic components to improve the reliability, organization, and usability of the overall system. These components handle connections between the main electronics, provide information during testing, and regulate power for the robot’s different systems.

The Waveshare Servo Driver Board was selected because it plugs directly into the Raspberry Pi Pico 2 W and provides convenient connections for the servo and motor driver. This reduces the number of loose jumper-wire connections, making the wiring more compact, secure, and easier to manage.

The Waveshare Pico-LCD-1.44 was added to provide on-robot status information and debugging without requiring a laptop. Its 128 × 128 SPI display and four buttons allow the team to view robot information and run test routines directly on the robot during testing.

The XL4015 buck converter was selected to efficiently reduce the battery voltage while producing less heat than a linear regulator. Its roughly 90%+ efficiency helps reduce wasted energy, which is important for a battery-powered robot. The converter was also positioned away from the IMU and I²C wiring to reduce the effects of switching noise.

# Final Circuit Architecture

<table>
  <tr>
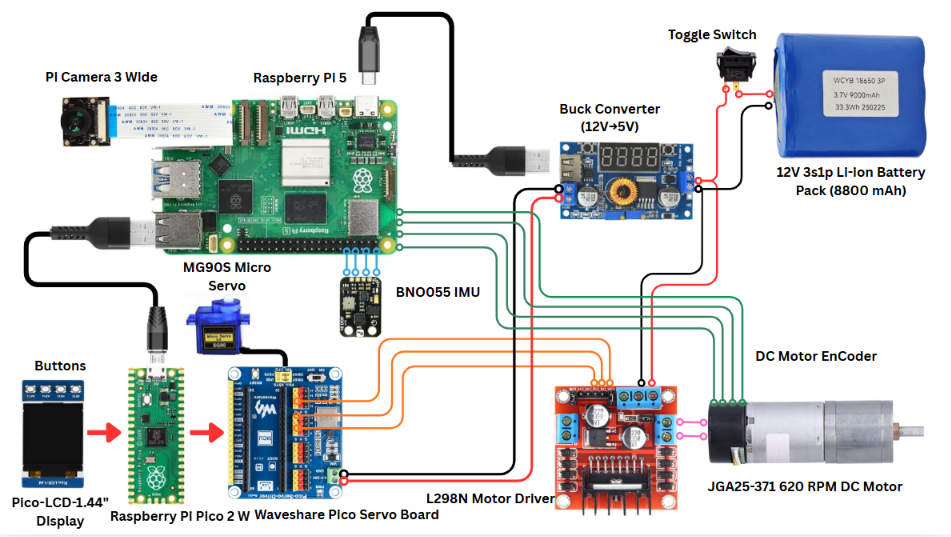
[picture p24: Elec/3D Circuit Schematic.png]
    <td align="center"><strong></strong><br></td>
  </tr>
</table> 

<table>
  <tr>
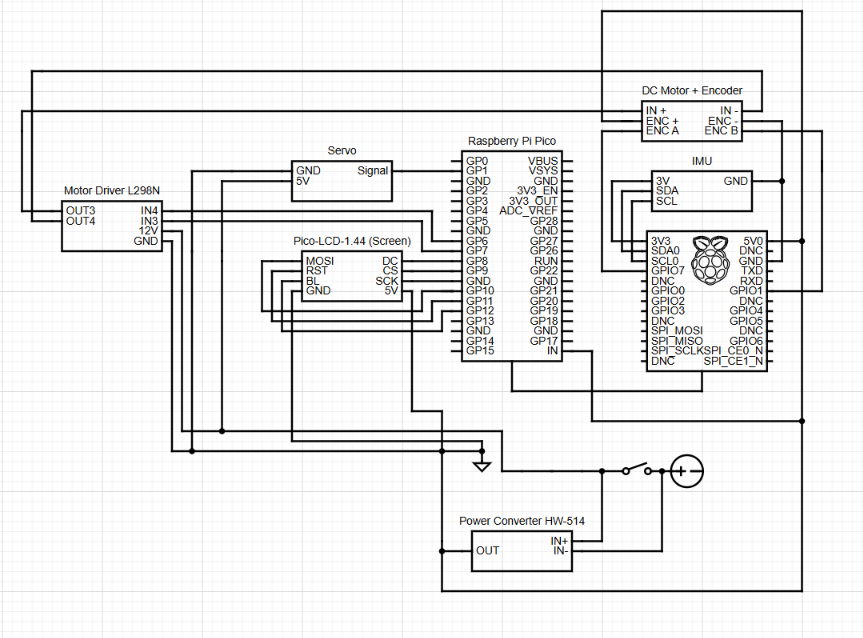
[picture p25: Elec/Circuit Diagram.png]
    <td align="center"><strong></strong><br></td>
  </tr>
</table> 

## Main Battery: 12V Li-ion Pack

<table>
  <tr>
    <td align="center"><strong></strong><br>
</td>
  </tr>
</table> 

A 12V Li-ion battery pack was selected to provide the required voltage for the drivetrain without needing a step-up converter. The battery provides enough capacity for the robot while fitting within the chassis without adding excessive weight.

The 12V output matches the nominal voltage of the drive motor and L298N motor driver, avoiding the added complexity and power losses of a step-up converter. The Li-ion chemistry also provides high energy density, allowing the required capacity to fit within the robot. Finally, the battery is mounted low and centrally in the chassis to improve stability and distribute the weight more evenly across the four wheels.

| Specification | 12V Li-ion Battery Pack |
|---|---|
| Chemistry | Lithium-ion |
| Nominal pack voltage | 12V |
| Rated capacity | 8800 mAh |
| Main advantage | Matches the drivetrain's 12V nominal voltage |
| Main disadvantage | Requires appropriate protection and charging procedures |

## Steering Servo: MG90S vs. SG90

| Specification | SG90 | MG90S |
|---|---|---|
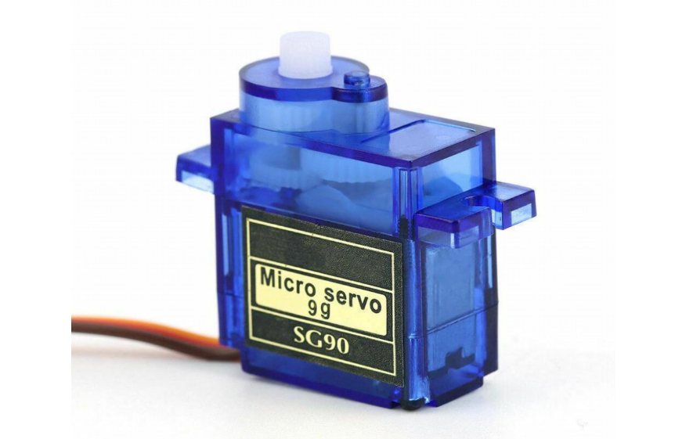
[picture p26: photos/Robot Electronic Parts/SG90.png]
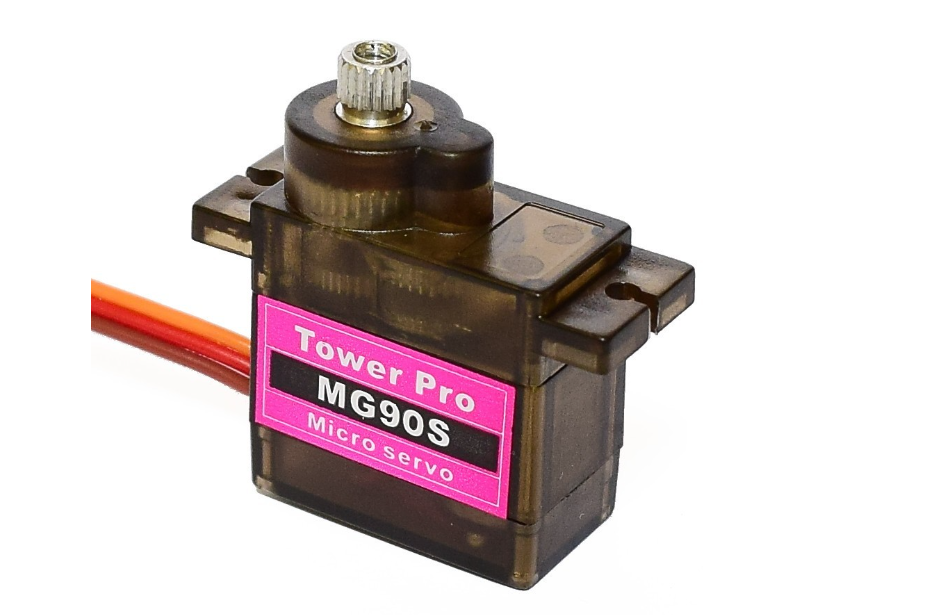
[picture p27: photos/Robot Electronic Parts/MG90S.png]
| Image |  |  |
| Description | The SG90 is a low-cost micro servo with plastic internal gears. It is easy to find and suitable for lightweight applications, but the plastic gears are more likely to strip under repeated stall or impact loads. This is a concern for steering because the servo can experience sudden loads when a wheel contacts a wall, pillar, or other obstacle. | The MG90S is similar in size to the SG90 but uses metal internal gears, making it better suited for the repeated mechanical loads experienced by the steering system. |
| Gear material | Plastic | Metal |
| Stall torque | Approximately 1.5–1.8 kg·cm at 4.8–6V | Approximately 1.8–2.2 kg·cm at 4.8–6V |
| Operating voltage | 4.8–6V | 4.8–6V |
| Main advantage | Very low cost and easy availability | Greater resistance to repeated stall and impact loads |
| Main disadvantage | Plastic gears can strip under heavy loading | Higher cost than the SG90 |

The MG90S was selected because steering can expose the servo to sudden mechanical loads. Its metal gear train provides greater durability than the plastic gears in the SG90. The higher cost was accepted because steering reliability was more important than saving a small amount on a component that could cause a mechanical failure during a run.

## Chassis Material: 3D-Printed PLA-CF

The chassis needs sufficient stiffness to maintain consistent camera, sensor, and steering geometry while the robot is moving. PLA-CF was selected because it provides this stiffness while still allowing the team to quickly modify and reprint parts as the design changed. The multi-layer structure also separates the high-current drivetrain components from the more sensitive sensing and computing electronics.

| Specification | 3D-Printed Chassis (PLA-CF) |
|---|---|
| Material | PLA reinforced with chopped carbon fibre |
| Structure | Multi-layer frame connected with brass standoffs |
| Reference cost | Approximately $25 CAD per spool |
| Main advantage | Stiff, relatively lightweight, and printable in-house |
| Main disadvantage | More abrasive on nozzles and requires a hardened nozzle |

## Wheels: LEGO Wheels and Tires

<table>
  <tr>
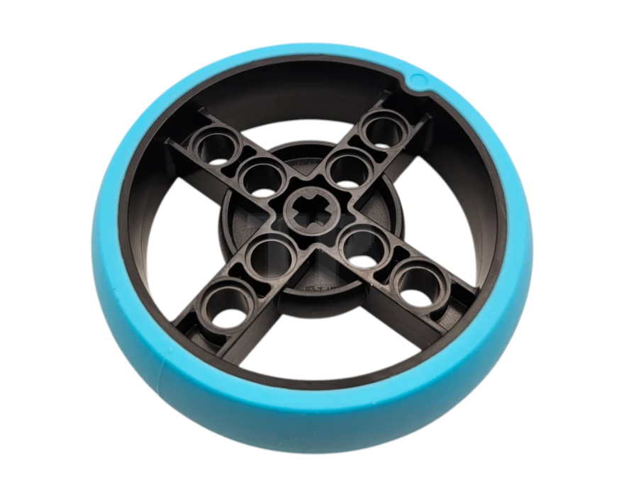
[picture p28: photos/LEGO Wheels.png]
    <td align="center"><strong></strong><br></td>
  </tr>
</table> 

Using LEGO wheels reduced the amount of mechanical design and testing required for the drivetrain. This allowed the team to focus development time on the chassis, steering geometry, and motor system. The main trade-off is that wheel size and tire options are limited to what is available within the LEGO ecosystem.

| Specification | LEGO Wheels, Axles and Connectors |
|---|---|
| Tire material | Rubber tire over a plastic hub |
| Axle interface | Standard LEGO Technic cross-axle |
| Reference cost | Approximately $50 CAD |
| Main advantage | Off-the-shelf wheel and axle system with reliable traction |
| Main disadvantage | Limited selection of wheel sizes compared with a custom system |

# Power System Architecture

## Two Board Architecture

The Raspberry Pi 5 acts as the robot’s main decision-making computer. It processes the vision input from the wide-angle camera and vehicle orientation input from the IMU and processes the higher-level logic in Python for lane following, obstacle avoidance, and the state machine. The Pi 5 sends movement commands to the Raspberry Pi Pico 2 W, which acts as the real-time controller.

The Pico runs a single program directly from flash instead of a full operating system, allowing it to handle low-latency control tasks reliably. It converts commands from the Pi 5 into low-level signals for the MG90S servo and L298N motor driver. The Pico can also send status information back to the Pi 5, allowing the two boards to communicate during operation.

### Why Two Boards?

The split is based on the strengths of each board:

- Pi 5 → High-level processing: camera processing, decision logic, and state machine.
- Pico 2 W → Real-time control: IMU reading, PWM generation, servo control, and motor commands.

This prevents heavy camera processing from interfering with the timing-sensitive steering and motor control.

### Power Distribution

The L298N motor driver receives power from the external battery and supplies the required current to the motor, since the Raspberry Pi Pico 2 W cannot safely power the motor directly. The Pico and other electronics use their appropriate regulated power supplies, while the motor receives power through the L298N.

All components share a common ground, which provides the same electrical reference for the control signals between the Raspberry Pi 5, Pico, and motor driver. This allows the control signals to be read reliably across the system.

## Power Distribution Diagram: Nominal Values

<table>
  <tr>
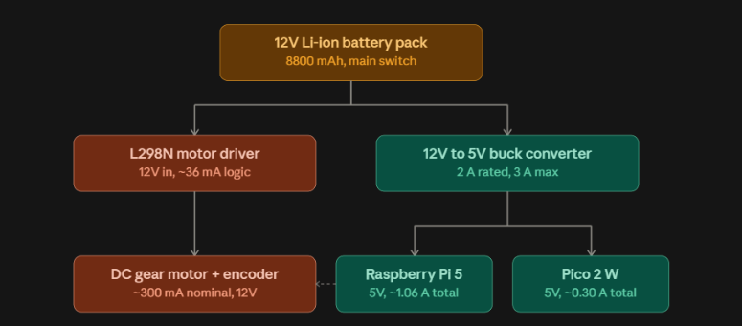
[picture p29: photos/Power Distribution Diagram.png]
    <td align="center"><strong></strong><br></td>
  </tr>
</table> 

<table>
  <tr>
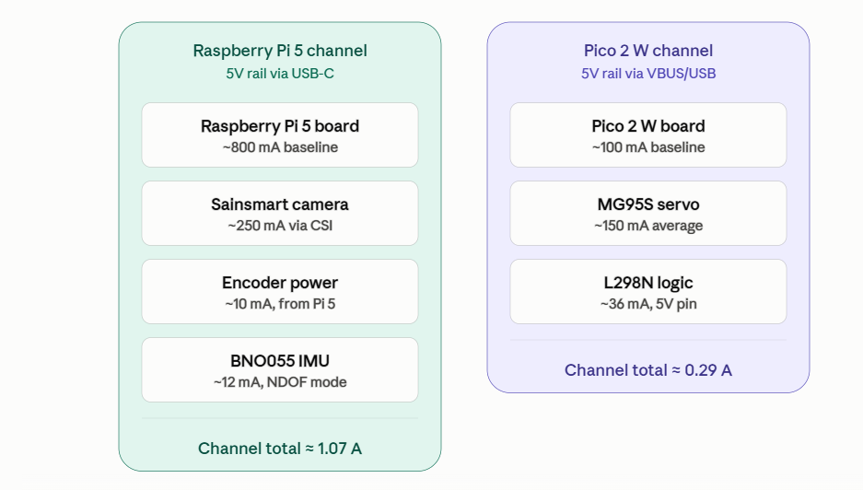
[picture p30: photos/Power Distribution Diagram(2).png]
    <td align="center"><strong></strong><br></td>
  </tr>
</table> 

## Nominal Current Draw for Each Part

| Part | Channel | Nominal Draw | Basis |
|---|---|---|---|
| Raspberry Pi 5 (board) | Pi 5 | ~800 mA @ 5 V | Idle draw is roughly 4 to 5 W, increasing toward 12 W under heavy CPU/USB load. |
| Sainsmart 5MP Camera | Pi 5 | ~250 mA | OV5647-based Raspberry Pi camera modules are commonly rated around 300 mA peak. The estimated running draw is slightly below this. |
| Encoder (Hall-effect) | Pi 5 | ~10 mA | Two-channel Hall-effect encoders on small gearmotors draw a maximum of about 10 mA. |
| BNO055 IMU | Pi 5 | ~12 mA | The maximum total supply current for the BNO055 is 12.3 mA. |
| Pi 5 channel total | — | ≈1.07 A | Sum of the four components above. |
| Raspberry Pi Pico 2 W (board) | Pico | ~100 mA @ 5 V | Community measurements for Pico/Pico W boards are typically in the 80 to 130 mA range. |
| MG90S Servo | Pico | ~150 mA average | These servos draw about 10 mA when idle and 120 to 250 mA while moving, with a stall current of up to about 800 mA. |
| L298N Logic Pin | Pico | ~36 mA | The L298N module's logic supply draws 0 to 36 mA. |
| Pico channel total | — | ≈0.29 A | Sum of the three components above. |
| Buck Converter Output | Both channels | ≈1.36 A | Sum of the Pi 5 and Pico channel totals. |
| DC Gear Motor | L298N | ~300 mA nominal (estimated) | A 12 V JGA25-370-style gearmotor draws about 50 mA at no load and up to 1200 mA when stalled. |

## Power Budget

### 5 V Power Requirement

The 5 V rail powers the Raspberry Pi 5 and the Waveshare expansion board hosting the Raspberry Pi Pico 2 W. The connected electronics require approximately 6.8 W. Accounting for approximately 85% buck converter efficiency, the battery must supply:

$$
P_{battery} = \frac{6.8W}{0.85} \approx 8.0W
$$

### Motor Power

The drive motor draws approximately 0.300 A at 12 V through the L298N motor driver.

$$
P_{motor} = 12V \times 0.300A = 3.6W
$$

Therefore, the estimated total system power is:

$$
P_{total} = 8.0W + 3.6W = 11.6W
$$

### Total System Requirement

At a nominal battery voltage of 12 V, the total system power corresponds to approximately:

$$
I_{battery} = \frac{11.6W}{12V} \approx 0.97A
$$

For a 3.0 Ah battery rated for 1C continuous discharge, the maximum continuous current is:

$$
I_{max} = 3.0Ah \times 1C = 3.0A
$$

The theoretical continuous runtime is:

$$
t = \frac{3.0Ah}{0.97A} \approx 3.1\text{ hours}
$$

## Why This Matters

- The Raspberry Pi 5 is the dominant load on the 5 V rail. At approximately 800 mA, it draws more than three times the current of the entire Pico channel combined. This means it accounts for most of the electronics power consumption, even though it is not directly responsible for moving the robot.
- The calculated 3.1-hour runtime is much longer than a WRO competition run, which typically lasts only a few minutes per heat. This gives the robot a large margin for real-world conditions such as voltage sag, increased motor load, stall current, and temporary steering-current spikes.
- At an estimated 0.97 A, the robot uses only about 32% of the battery's 1C continuous-discharge limit. This means the battery was not selected to operate close to its maximum current rating.

# Programming Logic

## Open Challenge Logic

The Open Challenge uses a combination of camera-based wall following and IMU heading control to navigate the field. The algorithm is as follows:

<table align="center">
  <tr>
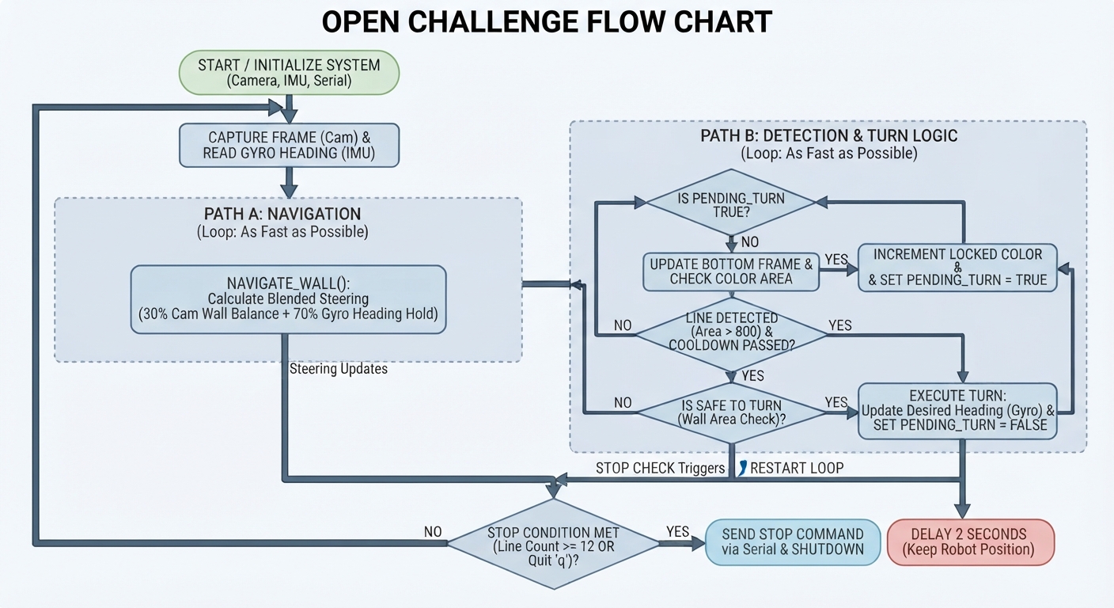
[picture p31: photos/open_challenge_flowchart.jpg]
    <td align="center"><strong></strong><br></td>
  </tr>
</table> 

### 1. Get Sensor Inputs

- The Raspberry Pi captures a 320 × 240 camera feed and reads the robot's heading from the BNO055 IMU.
- The camera uses separate ROIs to detect the left/right black walls and blue/orange turn markers.

### 2. Calculate Steering

- The camera calculates a steering correction based on the difference in wall area between the left and right sides.

`cam_steer = DEFAULT_STEER_ANGLE + KP * (left_area - right_area)`

- The IMU calculates a correction based on the difference between the current and desired heading.

`gyro_steer = DEFAULT_STEER_ANGLE - KP_GYRO * heading_error`

- The final steering value combines both corrections, with the IMU given a higher weight:

`steering_value = 0.7 * gyro_steer + 0.3 * cam_steer`

### 3. Clamp Steering

`steering_value = max(45, min(135, steering_value))`

This helps keep the steering within the Ackermann steering range.

### 4. Check for Bottom Lines

- Blue markers indicate a counter-clockwise turn and orange markers indicate a clockwise turn.
- The first detected colour locks the direction for the run.
- `SAFE_TURN_AREA` sets the minimum area needed before the robot makes a turn, helping it avoid turning too early in different course configurations.

```
IF left_area > SAFE_TURN_AREA:
    turn(direction)
```

<table align="center">
  <tr>
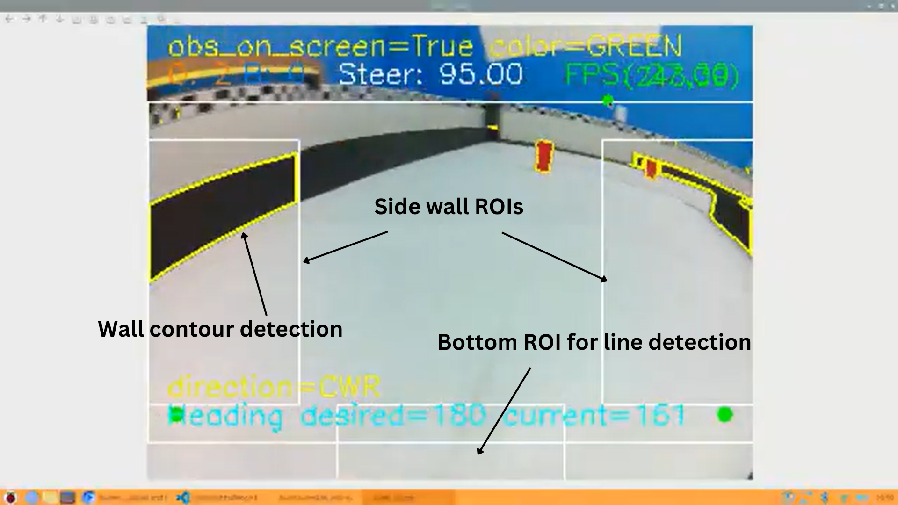
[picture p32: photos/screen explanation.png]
    <td align="center"><strong></strong><br></td>
  </tr>
</table>

## Obstacle Challenge Code

The obstacle avoidance system was developed through **two distinct iterations**. Iteration 1 was the original obstacle avoidance approach. After testing revealed several problems, the system was redesigned in Iteration 2 to improve obstacle selection, gap detection, steering consistency, and recovery behaviour.

---

# Iteration 1 — Initial Obstacle Avoidance

The first iteration used colour detection to identify red and green obstacles and attempted to determine a suitable path around them using the obstacle position and the black walls.

<table align="center">
  <tr>
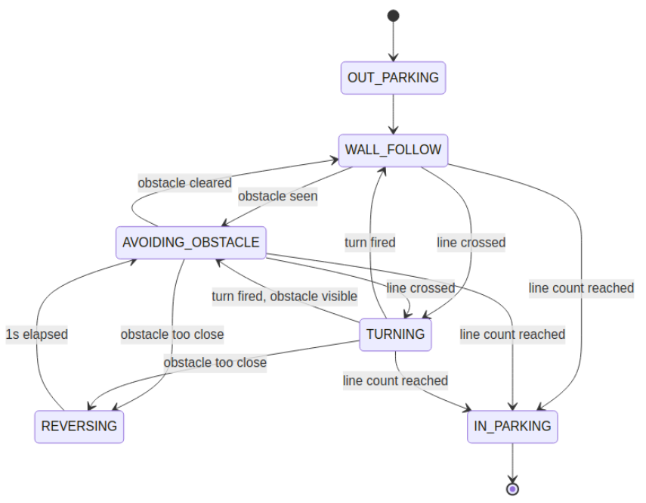
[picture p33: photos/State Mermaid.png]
    <td align="center"></td>
  </tr>
</table>

### 1. Detect an Obstacle

A dedicated `middle_frame` ROI spanning the full frame width was used to detect red and green contours.

An obstacle was detected when either colour exceeded the detection threshold:

```python
obs_on_screen = red_area > 100 or green_area > 100
```

The robot entered `AVOIDING_OBSTACLE` from `WALL_FOLLOW` as soon as either area crossed the threshold, unless a turn was already pending.

---

### 2. Select the Obstacle to React To

The original system used the **area of the detected obstacle** to estimate which obstacle was closest.

Contours were detected for both red and green obstacles, and the obstacle with the largest detected area was treated as the closest obstacle.

#### Problem

Using obstacle area as a distance measurement was unreliable.

When an obstacle became very close to the robot, part of the obstacle could leave the camera's field of view. This caused its detected contour area to become smaller even though the obstacle was actually closer.

As a result, the robot could incorrectly determine which obstacle was the closest when multiple obstacles were visible.

---

### 3. Determine the Passing Side

The obstacle colour was used to determine which side the robot should pass:

- **GREEN:** Pass on the left.
- **RED:** Pass on the right.

The appropriate corner of the obstacle's bounding box was used as the reference:

- **GREEN:** Bottom-left corner
- **RED:** Bottom-right corner

#### Problem

The obstacle colour correctly indicated which side the robot should pass, but using the obstacle corner alone did not provide enough information about the available gap.

The robot needed to determine where the opposite wall was so that it could estimate a suitable position to steer through.

---

### 4. Find the Gap to Steer Through

The original approach searched for the black wall on the opposite side of the obstacle.

A band of rows around the obstacle's own row was searched in the opposite wall's ROI for the nearest black pixel. The detected position was stored as:

```python
black_wall_x
```

This was then used to calculate a target point for the robot.

#### Problem

This method was inconsistent because **black pixels were present throughout the course**, not only on the walls.

Black lines and other black areas could be detected as the wall. The detected position could also change depending on the robot's angle.

This caused `black_wall_x` to change unexpectedly, which resulted in an inconsistent target point.

The robot could therefore steer toward the wrong position even though the obstacle itself had been detected correctly.

---

### 5. Steer Toward the Gap

The camera error was calculated relative to the centre of the frame:

```python
cam_error = target_x - frame_center_x
```

Steering was calculated using a proportional controller:

```python
steering = DEFAULT_STEER_ANGLE + KP_OBSTACLE * cam_error
```

The steering angle was limited to the mechanical range:

```python
steering = max(45, min(135, steering))
```

The obstacle avoidance controller used **camera-only steering**, with no gyro blending.

#### Problem

The proportional controller itself was not the primary problem.

The problem was that the `target_x` value could be incorrect because it depended on the unreliable black-wall detection.

Therefore, the controller could correctly steer toward an incorrect target.

---

### 6. Safety Check

A safety check was used to determine when an obstacle was too close.

If the obstacle was on the wrong side and its bottom edge had passed **75% of the ROI height**, the obstacle was considered too close.

The robot then entered the `REVERSING` state and backed up for **1 second**.

#### Problem

Without a recovery behaviour, the robot could continue driving toward an obstacle when there was no longer enough space to safely steer around it.

The reversing behaviour was therefore necessary to prevent the robot from becoming stuck against an obstacle.

---

### 7. Check if the Obstacle Was Cleared

The robot checked whether it had reached the desired position beside the obstacle:

```python
obstacle_reached = (
    abs(cam_error) < OBSTACLE_REACHED_PX
    and abs(cam_error_y) < OBSTACLE_REACHED_PY4
)
```

The obstacle was considered avoided when it was either completely out of view or `obstacle_reached` was true while the obstacle was still visible.

Once cleared, the robot returned to:

```text
WALL_FOLLOW
```

#### Problem

Simply waiting for the obstacle to disappear from the camera was not always sufficient.

The robot needed to confirm that it had actually moved into the desired position beside the obstacle before returning to normal wall following.

---

# Iteration 2 — Improved Obstacle Avoidance

Testing Iteration 1 revealed that the main problems were with **distance estimation, target calculation, and inconsistent wall detection**.

Iteration 2 changed these parts of the system while retaining the colour-based obstacle detection and camera-based steering.

<table align="center">
  <tr>
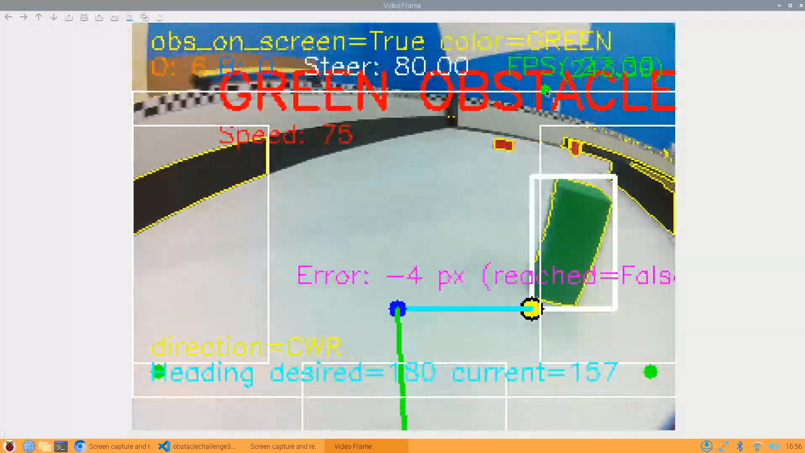
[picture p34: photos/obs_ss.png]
    <td align="center"></td>
  </tr>
</table>

### 1. Detect an Obstacle

The original colour detection system was retained.

A dedicated `middle_frame` ROI spanning the full frame width detects red and green contours.

```python
obs_on_screen = red_area > 100 or green_area > 100
```

The robot enters `AVOIDING_OBSTACLE` when either colour exceeds the detection threshold, unless a turn is already pending.

#### Why This Was Retained

The colour detection successfully identified the red and green obstacles, so this part of the original system did not require a major change.

---

### 2. Select the Closest Obstacle

#### Change — Area-Based → Bottom-Edge-Based

The original area-based distance measurement was replaced.

Contours were filtered to real obstacle blobs with an area greater than `400 px`.

The contours were then sorted according to the position of their bottom edge:

```python
closest_contour, obstacle_color = all_contours[0]
```

The obstacle whose bottom edge was closest to the bottom of the ROI was selected as the closest obstacle.

#### Why This Was Changed

The original area-based method could fail when a close obstacle was partially outside the camera's field of view.

The bottom edge provided a more reliable measurement because an obstacle moves lower in the camera frame as the robot approaches it.

This made the closest-obstacle selection more consistent.

---

### 3. Determine the Passing Side

The original colour-based passing logic was retained:

- **GREEN:** Pass on the left.
- **RED:** Pass on the right.

The appropriate bottom corner of the obstacle remained the reference point:

- **GREEN:** Bottom-left
- **RED:** Bottom-right

#### Why This Was Retained

The colour of the obstacle already provided a reliable indication of which side the robot should use, so this part did not need to be replaced.

---

### 4. Improve the Gap Calculation

#### Original Problem

The Iteration 1 system searched for `black_wall_x` to determine the opposite wall.

This was unreliable because other black pixels on the course could be mistaken for the wall.

#### Change — Position-Based Target

The black-wall search was removed.

Instead, the algorithm calculates a target point beside the obstacle based on the obstacle's position in the camera image.

The target distance changes depending on how close the obstacle is:

- **Closer obstacle → target point is placed farther from the obstacle.**
- **Farther obstacle → target point is placed closer to the obstacle.**

#### Why This Was Changed

This removes the dependency on detecting black pixels.

The target position is no longer affected by:

- Black lines elsewhere on the course
- Incorrect black-pixel detections
- Changes in the robot's angle
- Small changes in the detected wall position

This creates a more consistent and predictable gap for the robot to steer through.

---

### 5. Steer Toward the Gap

The camera error continues to be calculated relative to the centre of the frame:

```python
cam_error = target_x - frame_center_x
```

The proportional controller is retained:

```python
steering = DEFAULT_STEER_ANGLE + KP_OBSTACLE * cam_error
```

The steering angle remains limited to the safe range:

```python
steering = max(45, min(135, steering))
```

The obstacle avoidance controller remains **camera-only**, with no gyro blending.

#### Why This Was Retained

Testing showed that the proportional controller was not the main cause of the steering problems.

The main issue was the unreliable target position produced by the wall detection.

Once the target became more predictable, the same proportional controller could be used effectively.

---

### 6. Safety Check — Obstacle Too Close

The reversing safety system was retained.

If the obstacle is on the wrong side and its bottom edge has passed **75% of the ROI height**, the obstacle is considered too close.

The robot enters `REVERSING` and backs up for **1 second** before attempting the avoidance manoeuvre again.

#### Why This Was Retained

The reversing system provided a useful recovery mechanism when the robot approached an obstacle too closely.

It prevented the robot from continuing forward when there was insufficient space to safely complete the avoidance manoeuvre.

---

### 7. Check if the Obstacle Is Cleared

The obstacle-cleared check was retained:

```python
obstacle_reached = (
    abs(cam_error) < OBSTACLE_REACHED_PX
    and abs(cam_error_y) < OBSTACLE_REACHED_PY4
)
```

The obstacle is considered cleared when:

- The obstacle has completely left the camera's view, **or**
- `obstacle_reached` is true while the obstacle is still visible.

Once the obstacle has been cleared, the robot returns to:

```text
WALL_FOLLOW
```

#### Why This Was Retained

The position check provided a reliable way to confirm that the robot had moved beside the obstacle before returning to normal wall following.

https://github.com/user-attachments/assets/5943b1fa-faef-4a36-b9d3-321f097391a8

---

# Iteration Comparison

| Feature | Iteration 1 | Iteration 2 |
|---|---|---|
| Obstacle detection | Red/green colour detection | Red/green colour detection |
| Closest obstacle | Obstacle area | Bottom-edge position |
| Passing side | Obstacle colour | Obstacle colour |
| Reference point | Obstacle corner | Obstacle corner |
| Gap calculation | Black wall detection | Position-based target |
| Black wall detection | Yes | No |
| Target consistency | Inconsistent | More consistent |
| Camera angle sensitivity | Higher | Lower |
| Steering | Camera-only | Camera-only |
| Reversing | 1 second | 1 second |
| Obstacle-cleared check | Yes | Yes |

---

# Parking

**Iteration 2 was selected as the final obstacle avoidance approach.**

The main improvements were:

1. **Obstacle selection:** Changed from contour area to bottom-edge position because area became unreliable when close obstacles were partially outside the camera's view.
2. **Gap calculation:** Removed the black-wall search because other black features on the course could be detected as the wall.
3. **Target calculation:** Changed to a position-based target that adjusts according to the obstacle's distance in the camera frame.
4. **Steering:** Retained the proportional camera controller because the main issue was the target position, not the steering calculation.
5. **Safety and clearing:** Retained the reversing and obstacle-cleared checks because they provided useful recovery and state-transition behaviour.

The final system therefore uses **red/green colour detection, bottom-edge obstacle selection, position-based target generation, camera-only proportional steering, reversing protection, and obstacle-cleared detection**.

#### `OUT_PARKING`

`OUT_PARKING` is a **forced turn-out manoeuvre** used to leave the starting parking area.

- The robot starts by turning the steering to the required direction.
- It continues moving for a **fixed amount of time**.
- Because the manoeuvre is performed from a known starting position, no sensor-based steering decision is required.
- After the fixed movement is completed, the robot transitions into the main course navigation.

This provides a consistent way of exiting the starting parking area regardless of the camera or wall-following calculations.

#### `IN_PARKING`

`IN_PARKING` is the final parking manoeuvre and begins after the robot has passed the **12th line**.

The robot uses the black line/wall detection to determine when to begin each part of the parking manoeuvre.

1. After passing the **12th line**, the robot continues forward until the detected black area reaches a predetermined position in the camera frame.
2. Once the black area reaches this position, the robot performs a **forced turn** into the parking area.
3. The robot then continues moving forward until the black area reaches another predetermined position.
4. The robot stops its forward movement.
5. The steering is turned to the **maximum angle on one side**, and the robot reverses. This begins to swing the rear of the robot into the parking position.
6. The robot then reverses again while steering in the opposite direction, similar to how a real car performs a multi-point parking manoeuvre.
7. Once the final parking position is reached, the robot stops.

The parking sequence is therefore based on **predetermined sensor positions and fixed steering movements**, rather than normal wall-following. This allows the robot to perform a controlled multi-step manoeuvre to position itself inside the final parking area.

### Running the Program

To run the program without a connected display, ensure that the `SHOW_VID` variable is set to `False`. The working open challenge code is openchallenge.py under Code and the working obstacle challenge code is obstaclechallenge.py under Code.
### Running the Program on Startup

The robot can be configured to automatically start the challenge program when the Raspberry Pi boots using `crontab`.

Open the root crontab using:

    sudo crontab -e

Add the following line to the end of the crontab, replacing `<path/to>` with the path to the challenge file:

    @reboot /usr/bin/python3 <path/to>/obs_ch.py >/dev/null 2>&1 &

This command automatically runs the Python program whenever the Raspberry Pi starts.

By default, the `>/dev/null 2>&1` portion redirects all standard output and error messages to `/dev/null`, meaning they will not be saved or displayed. For debugging purposes, a log file can instead be created using:

    sudo touch /dev/cronlog

The crontab command can then be modified to redirect output to this file, allowing debug messages and errors to be reviewed.

### CAD and Wiring Files

All STL files and images of the parts used for the robot's CAD and 3D-printed components are included in the repository under the [Models](https://github.com/vaishvi-shah/wro-fe-2026/tree/main/models) folder. wiring diagrams are also provided, allowing the robot's physical structure and electronic connections to be reproduced alongside the software and challenge implementations.

## Step-by-Step Assembly Guide

Explosive 3d View of Robot:
<table align="center">
  <tr>
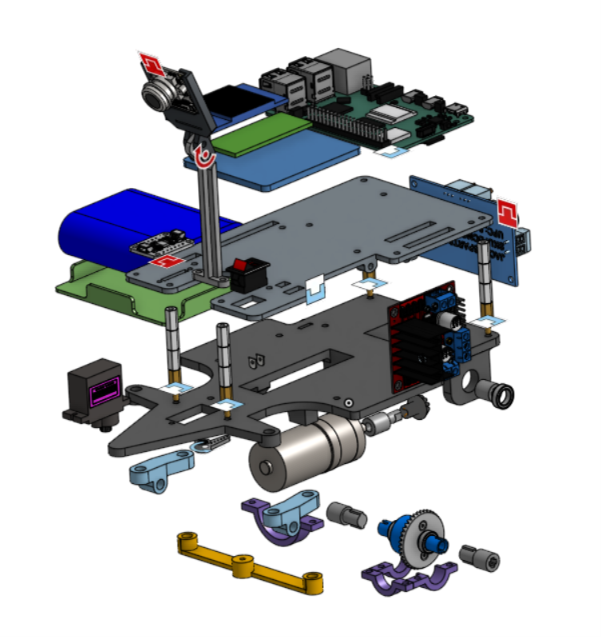
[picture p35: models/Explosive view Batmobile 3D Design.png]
    <td align="center"><strong></strong><br></td>
  </tr>
</table>

### 1. Print the Chassis
Print both chassis layers from models/Model STLs. 

---

### 2. Assemble the Drivetrain

- Mount the **WLToys 144001 differential (2:1 reduction)** to the rear axle using the custom **differential → axle coupler**.
- Install the **DC gear motor (9.6:1 gearbox)** using the custom **motor → gear coupler**.

The 9.6:1 gearbox was selected because:

- **4.4:1:** Insufficient torque
- **46.8:1 and 100:1:** Too slow

Mount the motor in the reworked motor bay, which includes:

- Extended length
- Access hole for mounting screws
- Tightened clamp
- 0.25 mm reduced mounting diameter

---

### 3. Assemble the Steering

- Mount the **MG95S servo** using the dedicated printed mounting holes.
- Install the **Ackermann steering linkage**.

> Do **not** use the previous LEGO steering geometry.

Before wiring:

1. Move the steering by hand.
2. Confirm the full mechanical range of approximately **45°–135°**.

This range is important because all steering calculations in software are clamped to these physical limits.

---

### 4. Mount Layer 1 Components

Install:

- Battery (centered and flat)
- L298N motor driver
- Servo
- Camera mount
  
#### Camera Position
- Front of chassis
- Angled downward
- Mounted high for a longer sight line

### 5. Mount Layer 2 Components

Install:

- Raspberry Pi 5
- Raspberry Pi Pico 2 W
- BNO055 IMU

Keep these components away from battery and motor wiring to reduce electrical noise and improve IMU reliability.

---

### 6. Wire the Power System

- Connect the **12 V 3S1P Li-ion battery (8800 mAh)** through the main power switch.

> Required by **WRO Rule 9.10**.

- Feed a **12 V → 5 V buck converter** to power:
  - Raspberry Pi 5
  - Raspberry Pi Pico 2 W
  - Camera
  - Servo electronics

- Supply motor power directly from the battery through the **L298N motor driver**.

> The Pico cannot safely provide the required motor current.

#### Wiring Recommendations

- Use terminal blocks instead of twisted wire joints.
- Connect all grounds together to create a common reference.

---

### 7. Wire Control Signals

Connect components according to the circuit diagram:

| Device | Connection |
|---|---|
| BNO055 IMU | Pico (I²C) |
| MG95S Servo | Pico PWM pin |
| L298N | Pico GPIO |
| Pico LCD (optional) | Pico SPI |

> The Pico LCD is intended for bench debugging only.

---

### 8. Attach the Front Bumper

Install the front bumper to protect:

- Camera
- Steering linkage

from impacts with walls and pillars.

---

### Important note. 

Images of how every part connects for each iteration is available under the photos folder. Ensure you look under Batmobile Iteration 3 not the older iterations.

---

### 9. Calibrate Before Every Run

Place the robot on the starting line and keep it stationary while the **BNO055 IMU calibrates**.

This provides:

- A clean heading reference
- Reduced gyro drift
- More accurate state machine behaviour

---

### 10. Bench Test Before Full Track Runs

Verify:

- Raspberry Pi 5 ↔ Pico communication
- Servo movement (**50°–130°**)
- Motor direction
- Motor speed control

If no display is connected:

```python
SHOW_VID = False
```

If:

```python
SHOW_VID = True
```

and no display is attached, the program will attempt to open a video window and generate an error.

---

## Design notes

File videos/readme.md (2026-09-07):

# Videos

### Summary Video

<a href="https://www.youtube.com/watch?v=VKRCWfLhV6I">
  Watch video
</a>

Click above to watch our video!

### Open Challenge Videos

https://github.com/user-attachments/assets/b752e2d7-2efb-4881-ae9d-5aae1f4fcaa4

### Obstacle Video

https://github.com/user-attachments/assets/9520dfca-cd9e-48ff-8d53-4761ecfdaf9c

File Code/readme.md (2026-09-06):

# Source Code
---
Main code for open challenge and obstacle challenge is directly in this folder

Additionally, these folders contain
* lib - custom helper classes and files
* pico - code for the pico microcontroller unit
* testers - files used to unit test the code
* utils - utilities used in development or testing the system

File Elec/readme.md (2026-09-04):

# Electrical and Electronic Schematics

<table>
  <tr>
    <td><strong>Electronics Schematic</strong><br>Electronics Schematic</td>
  </tr>
  <tr>
    <td><strong>Electronic connections</strong><br>Electronics Connections</td>
  </tr>
</table>

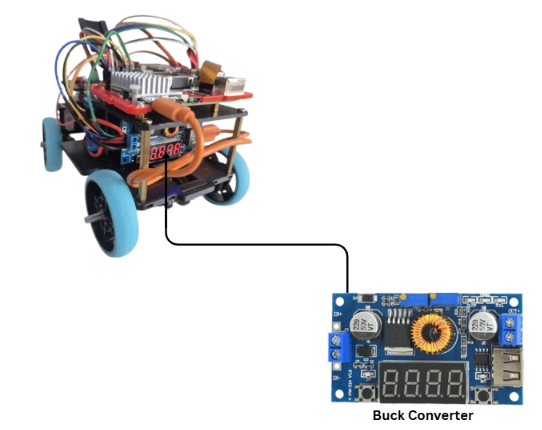
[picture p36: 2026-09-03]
photos/Electronic Part Position/Back View.png

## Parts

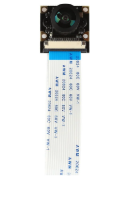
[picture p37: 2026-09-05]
photos/Robot Electronic Parts/Pi Camera 3 Wide.png

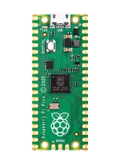
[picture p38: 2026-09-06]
photos/Robot Electronic Parts/Raspberry Pi Pico 2 W.png

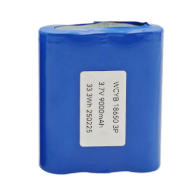
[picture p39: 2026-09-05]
photos/Robot Electronic Parts/12V Lithium Battery.png

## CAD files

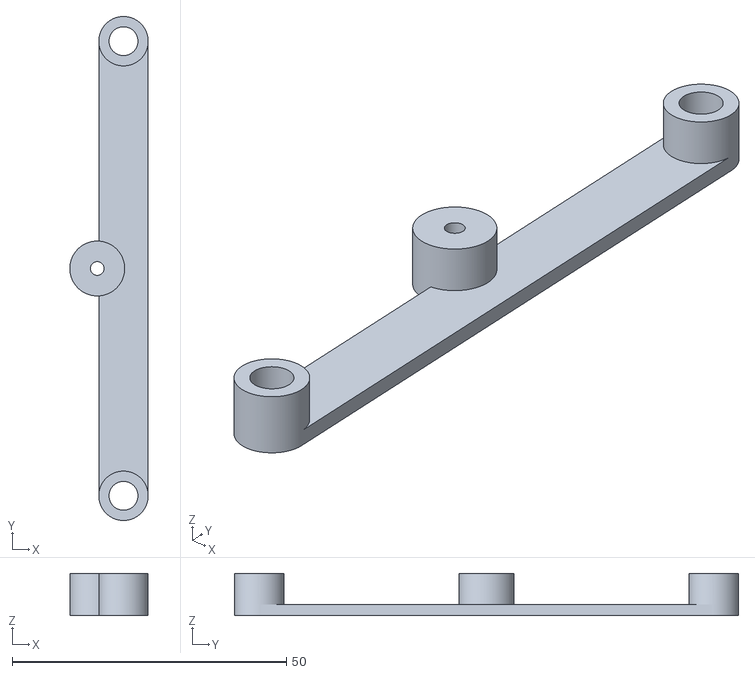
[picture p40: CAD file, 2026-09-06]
models/Model STLs/Connector Ackermann.stl
14.3 x 91.8 x 7.70

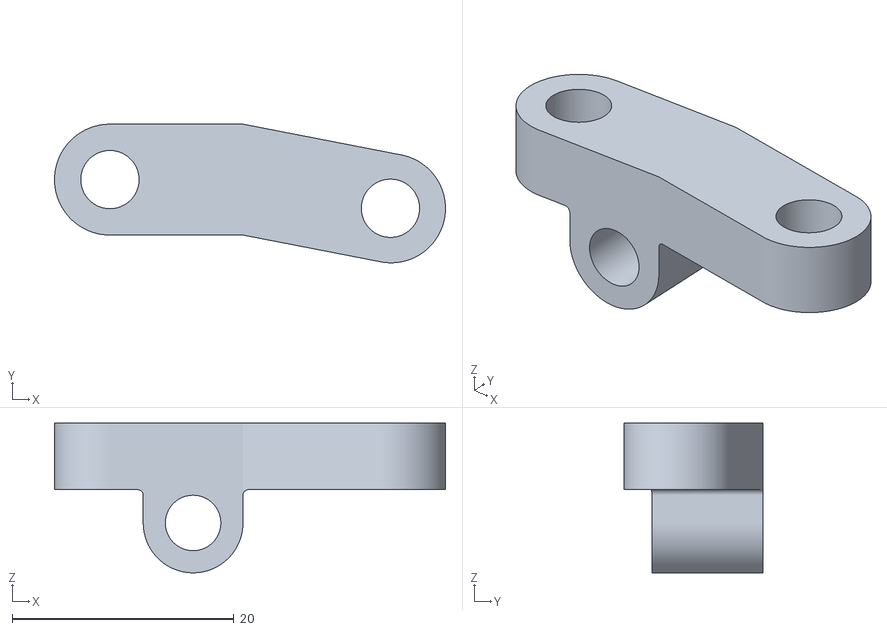
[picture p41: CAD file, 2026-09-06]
models/Model STLs/Chassis Base - Right Steering Linkage.stl
35.3 x 12.5 x 13.5

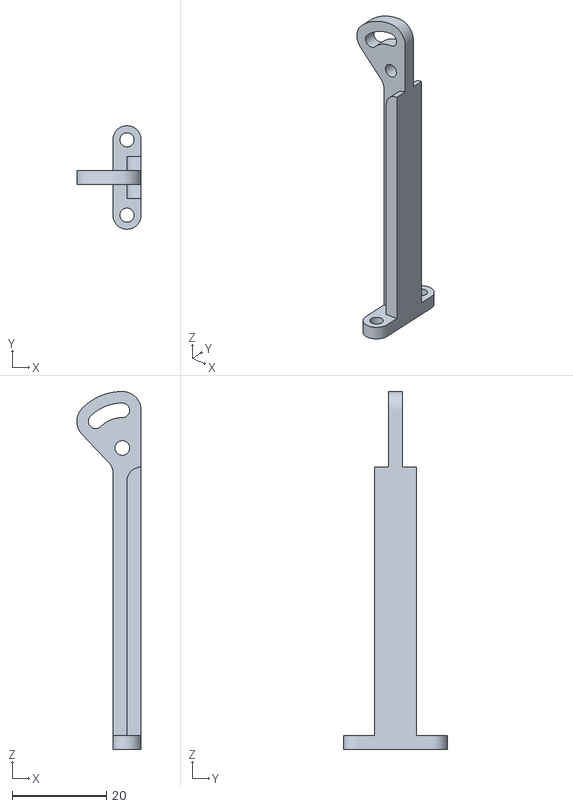
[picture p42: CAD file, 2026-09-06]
models/Model STLs/Chassis Base - Camera Mount Base.stl
13.7 x 22.0 x 76.1

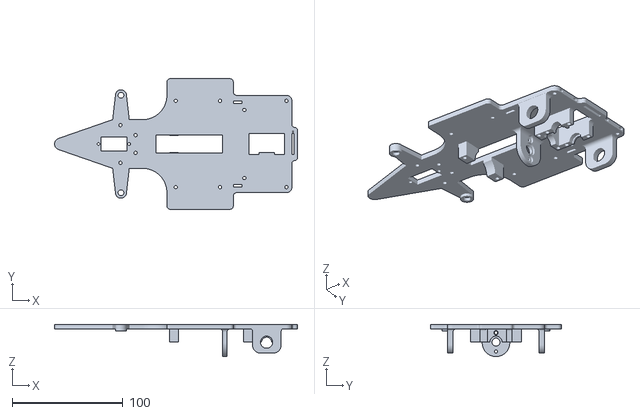
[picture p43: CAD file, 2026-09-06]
models/Model STLs/Chassis Base - Chassis Base.stl
219.6 x 118.0 x 29.0

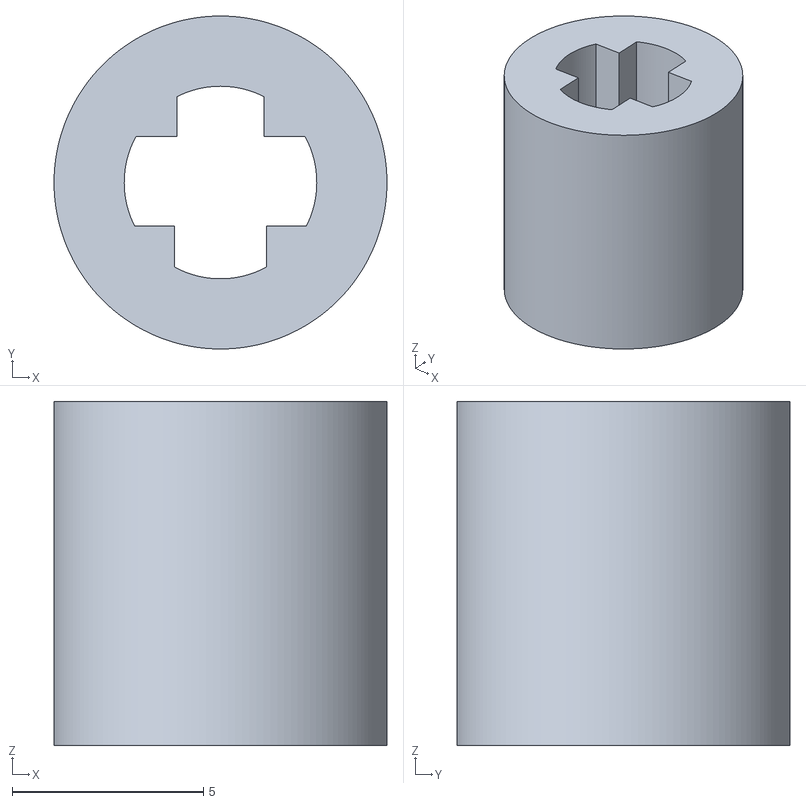
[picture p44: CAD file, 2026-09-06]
models/Model STLs/Axle Connector 1.stl
8.70 x 8.70 x 9.00

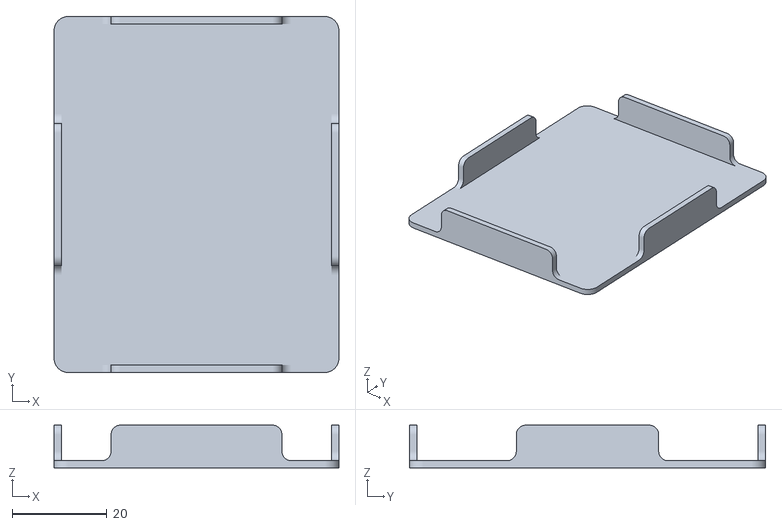
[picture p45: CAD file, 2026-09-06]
models/Model STLs/Chassis Base - Battery Well V2.stl
60.0 x 75.0 x 9.00

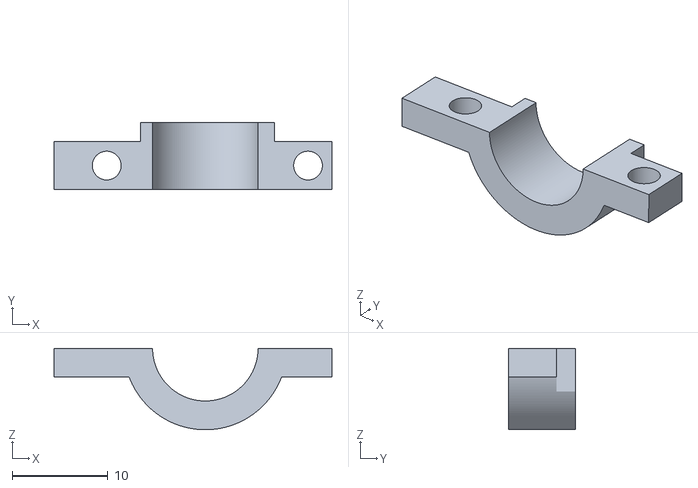
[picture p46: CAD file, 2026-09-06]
models/Model STLs/Chassis Base - Left Differential Bearing Clamp.stl
29.0 x 7.00 x 8.50

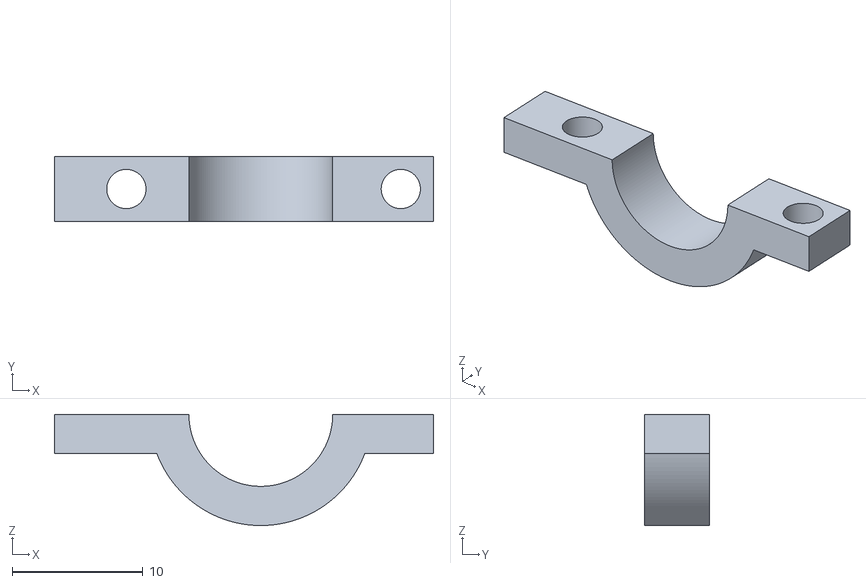
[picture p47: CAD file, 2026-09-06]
models/Model STLs/Chassis Base - Right Differential Bearing Clamp.stl
29.0 x 5.00 x 8.50

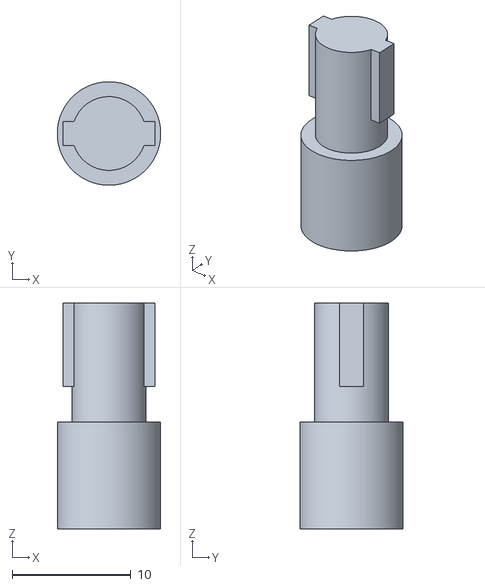
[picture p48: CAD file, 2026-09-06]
models/Model STLs/Axle Connector 3.stl
8.70 x 8.70 x 19.0

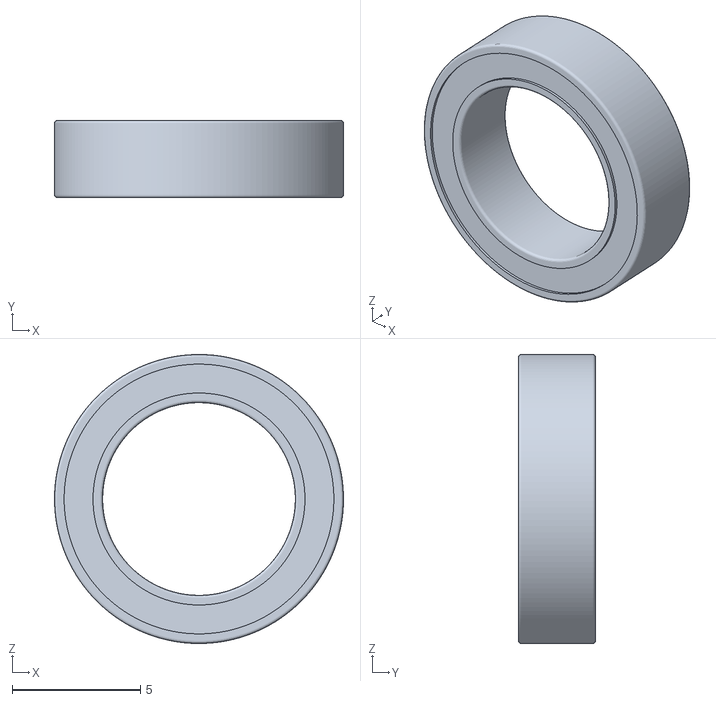
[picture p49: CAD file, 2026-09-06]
models/Model STLs/Bearing.stl
11.2 x 3.00 x 11.2

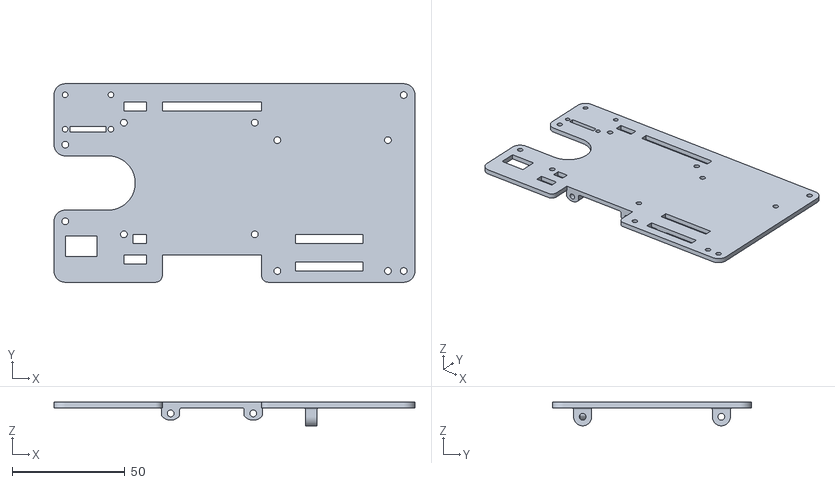
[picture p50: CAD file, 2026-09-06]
models/Model STLs/Chassis Base - Layer 2.stl
160.0 x 88.0 x 10.5

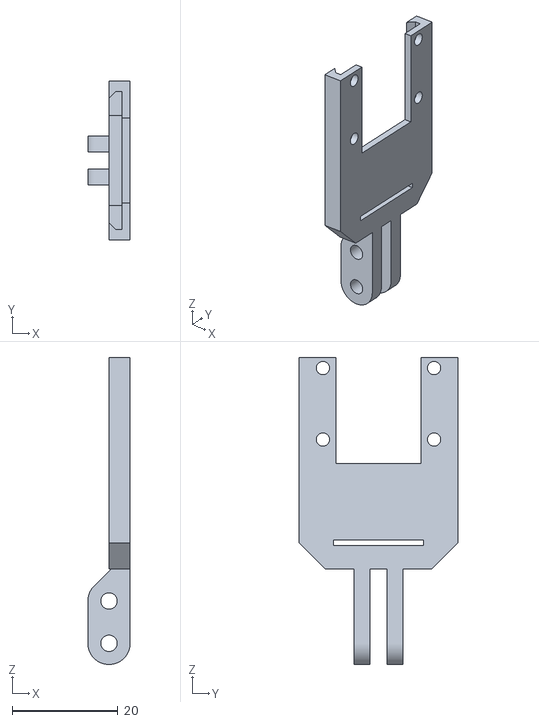
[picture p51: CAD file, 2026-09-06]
models/Model STLs/Chassis Base - Camera Mount.stl
8.00 x 30.0 x 58.0

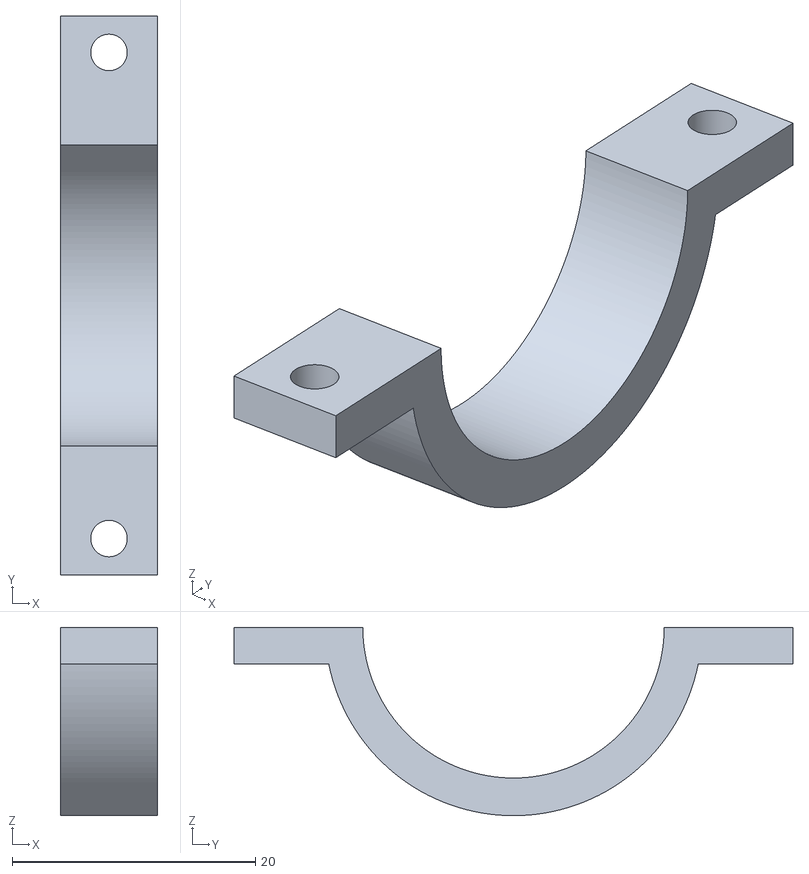
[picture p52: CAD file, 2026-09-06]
models/Model STLs/Chassis Base - DC Motor Clamp.stl
8.00 x 46.0 x 15.5

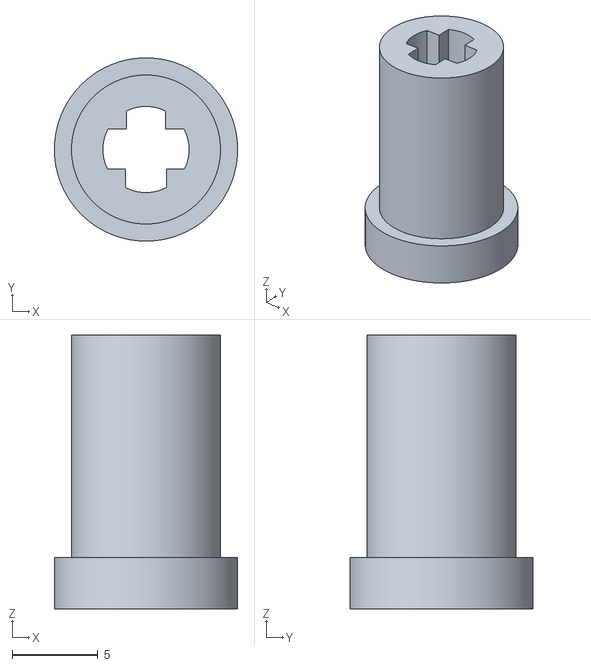
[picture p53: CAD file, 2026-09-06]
models/Model STLs/Axle Connector 2.stl
10.7 x 10.7 x 16.0

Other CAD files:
models/Model STLs/Chassis Base - Driving Gear Bearing Clamp.stl

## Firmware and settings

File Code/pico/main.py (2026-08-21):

from machine import Pin, SPI, PWM
import framebuf
import time
import sys
import uselect
import utime

# 1. Setup Pins
# ENA controls speed using Pulse Width Modulation (PWM)
ena = machine.PWM(machine.Pin(4))
ena.freq(1000) # Set PWM frequency to 1kHz

# IN1 and IN2 control the motor direction
in1 = machine.Pin(6, machine.Pin.OUT)
in2 = machine.Pin(7, machine.Pin.OUT)

# 
BL = 13
DC = 8
RST = 12
MOSI = 11
SCK = 10
CS = 9

class LCD_1inch44(framebuf.FrameBuffer):

    def __init__(self):

        self.width = 128
        self.height = 128

        self.cs = Pin(CS, Pin.OUT)
        self.rst = Pin(RST, Pin.OUT)

        self.spi = SPI(
            
            1,
            baudrate=40000000,
            polarity=0,
            phase=0,
            sck=Pin(SCK),
            mosi=Pin(MOSI),
            miso=None
        )

        self.dc = Pin(DC, Pin.OUT)

        self.buffer = bytearray(self.width * self.height * 2)

        super().__init__(self.buffer, self.width, self.height, framebuf.RGB565)

        self.init_display()
        
        self.black = 0x0000
        self.white = 0xFFFF
        self.red   = 0xF800
        self.blue  = 0x07E0
        self.green = 0x001F
        

    def write_cmd(self, cmd):
        self.dc(0)
        self.cs(0)
        self.spi.write(bytearray([cmd]))
        self.cs(1)

    def write_data(self, data):
        self.dc(1)
        self.cs(0)
        self.spi.write(bytearray([data]))
        self.cs(1)

    def init_display(self):

        self.rst(1)
        time.sleep_ms(50)
        self.rst(0)
        time.sleep_ms(50)
        self.rst(1)
        time.sleep_ms(50)

        self.write_cmd(0x11)
        time.sleep_ms(120)

        self.write_cmd(0x36)
        self.write_data(0x70)

        self.write_cmd(0x3A)
        self.write_data(0x05)

        self.write_cmd(0x29)

    def show(self):

        self.write_cmd(0x2A)
        self.write_data(0x00)
        self.write_data(0x00)
        self.write_data(0x00)
        self.write_data(0x7F)

        self.write_cmd(0x2B)
        self.write_data(0x00)
        self.write_data(0x00)
        self.write_data(0x00)
        self.write_data(0x7F)

        self.write_cmd(0x2C)

        self.dc(1)
        self.cs(0)
        self.spi.write(self.buffer)
        self.cs(1)


# Backlight
pwm = PWM(Pin(BL))
pwm.freq(1000)
pwm.duty_u16(65535)

LCD = LCD_1inch44()
LCD.init_display()
poll = uselect.poll()
poll.register(sys.stdin, uselect.POLLIN)

# -------------------------
# BUTTONS
# -------------------------

btn_stop = Pin(2, Pin.IN, Pin.PULL_UP)
btn_obstacle = Pin(3, Pin.IN, Pin.PULL_UP)
btn_open = Pin(17, Pin.IN, Pin.PULL_UP)
btn_meme = Pin(15, Pin.IN, Pin.PULL_UP)

# Servo initialization
servo = PWM(Pin(1))
servo.freq(50)

def set_angle(angle):
    min_us = 500
    max_us = 2500

    pulse_us = min_us + (angle / 180) * (max_us - min_us)

    duty = int(pulse_us / 20000 * 65535)
    servo.duty_u16(duty)

def show_message(msg, color):

    LCD.fill(color)

    LCD.text(msg, 10, 60, LCD.white)

    LCD.show()

def motor_forward(speed):
    """Moves the motor forward at a specific speed (0 to 100)."""
    in1.value(1)
    in2.value(0)
    # MicroPython PWM duty cycle goes from 0 to 65535
    duty_cycle = int((speed / 100) * 65535)
    ena.duty_u16(duty_cycle)
    print(f"Moving Forward at {speed}% speed")

def motor_backward(speed):
    """Moves the motor backward at a specific speed (0 to 100)."""
    in1.value(0)
    in2.value(1)
    duty_cycle = int((speed / 100) * 65535)
    ena.duty_u16(duty_cycle)
    print(f"Moving Backward at {speed}% speed")

def motor_stop():
    """Turns the motor off."""
    in1.value(0)
    in2.value(0)
    ena.duty_u16(0)
    print("Motor Stopped")
    

def handle_motor_commands(direction, speed_str, angle_str, line, state):
    try:
        speed = int(speed_str)
        angle = int(angle_str)
        
        set_angle(angle)
        
        if direction == "FWD":
            motor_forward(speed)
        elif direction == "BWD":
            motor_backward(speed)
        elif direction == "STOP":
            motor_stop()
    except ValueError:
        print("Data conversion error")

def clear_screen():
    LCD.fill(LCD.black)
    LCD.show()
    

def btn_open_close(ser_value, speed_value, direc, line_col, sta ):
    clear_screen()
    
    LCD.text("SerV: " + ser_value, 10, 10, LCD.white)
    LCD.text("SpV: " + speed_value, 10, 30, LCD.white)
    LCD.text("Dir:" + direc, 10, 50, LCD.white)
    LCD.text("LC:" + line_col, 10, 70, LCD.white)
    LCD.text("St:" + sta, 10, 90, LCD.white)
                    
    LCD.show()
    time.sleep(0.3)

while True:
    
    show_message("Welcome!!!", LCD.green)


    # -------------------------
    # OPEN BUTTON
    # -------------------------
    if btn_open.value() == 0:     
        show_message("Open", LCD.green)
        print("Open")        
        time.sleep(0.3)
            
    # -------------------------
    # OBSTACLE BUTTON
    # -------------------------
    elif btn_obstacle.value() == 0:
        
        show_message("Obstacle", LCD.green)
        print("Obstacle")
        time.sleep(1)
        

    # -------------------------
    # STOP BUTTON
    # -------------------------
    elif btn_stop.value() == 0:
#         motor_stop()
 
        show_message("STOP", LCD.red)
        #LCD.Paint_DrawLine(0, 10, 127, 10, LCD.black, 2, 0)
        print("Stop")
        time.sleep(0.3)
            
    # -------------------------
    # Team Name BUTTON
    # -------------------------
    elif btn_meme.value() == 0:
# THis is the message being sent from the Pico to Raspberry Pi 
        print("SENT Team Name")

        show_message("SENT Team Name", LCD.black)

        time.sleep(0.3)
    
    
    
    
    # =====================================
    # RECEIVE FROM PI (NON-BLOCKING)
    # =====================================
    
    poll = uselect.poll()
    poll.register(sys.stdin, uselect.POLLIN)
    
    
    
    if poll.poll(0):
        line = sys.stdin.readline().strip()
            
        if "," in line:

            try:
                servo_value, speed_val, direction, line_color, state = line.split(",")
                btn_open_close(servo_value, speed_val, direction, line_color, state)
                
                # This calls the function we defined at the top!
                handle_motor_commands(direction, int(speed_val), int(servo_value), int(line_color), state)
                    
            except ValueError:
                print("Error splitting data:", line)   

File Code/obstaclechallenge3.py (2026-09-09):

# 1 ----------------------------------------------------------------------------------------
"""
make the parking square size and location the sam I REMOVED THE THE 3 DEGREE THING -- CHECK CHECK CHECK
increased all speed by 7
"""


# imports!
import cv2
import numpy as np
from picamera2 import Picamera2
from lib.frames import Frame
import time
import serial
import lib.bno055 as bno055
import board
import adafruit_vl53l0x
from enum import Enum
import lib.motor_control as motor_control


class State(Enum):
    """Drive-mode only. TURNING is a first-class member and takes priority
    over WALL_FOLLOW/AVOIDING_OBSTACLE: as soon as a colour-line trips
    pending_turn, the main loop dispatches into run_turning() every frame
    instead of either of those, until the turn actually executes (or times
    out). REVERSING is still checked ahead of it, so an in-progress
    proximity-safety backup isn't cut short mid-manoeuvre -- see the
    dispatch order in the main loop."""
    OUT_PARKING = "OUT_PARKING"  # one-time manoeuvre at startup, before WALL_FOLLOW ever runs -- see out_parking_start
    WALL_FOLLOW = "WALL_FOLLOW"
    AVOIDING_OBSTACLE = "AVOIDING_OBSTACLE"
    TURNING = "TURNING"  # executing a pending colour-line turn -- see pending_turn and run_turning()
    REVERSING = "REVERSING"
    IN_PARKING = "IN_PARKING"  # entered once LINE_COUNT is reached, instead of stopping


CALIBRATION_FILE = "lib/bno055_calibration.json"
bno055.initialize()            # boot the IMU over I2C
sensor = bno055.sensor
bno055.load_calibration()      # apply saved accel/gyro/mag offsets if present

# ToF (VL53L0X) shares the same I2C bus as the IMU (IMU=0x28, ToF=0x29, see tof_tester.py) --
# activated right here alongside it, not lazily later, since board.I2C() must be grabbed
# once the bus is already up. Wrapped so a missing/failed ToF doesn't take the whole
# script down -- tof stays None and get_tof_distance() below just reports unavailable.
tof = None
try:
    tof_i2c = board.I2C()
    tof = adafruit_vl53l0x.VL53L0X(tof_i2c)
    print(f"INFO: ToF (VL53L0X) Initialized. Distance: {tof.range} mm")
except Exception as tof_e:
    print(f"WARNING: ToF (VL53L0X) initialisation failed: {tof_e}")
    tof = None


def get_tof_distance():
    """Returns the current ToF range in mm, or None if unavailable."""
    if tof:
        try:
            return tof.range
        except Exception:
            return None
    return None


controller = "FWD"
sent_steer = 0
sent_speed = None    # last speed actually sent -- a phase/state transition that changes speed or
sent_controller = None  # conqtroller (e.g. FWD->BWD) without also moving steering by >=3 must still
                        # resend, or the robot keeps executing whatever was last physically sent
SHOW_VID = True                 # toggle live OpenCV preview window
DEFAULT_STEER_ANGLE = 90        # neutral/straight steering angle, sent _as 100 + this
LINE_COUNT = 12                  # number of colour-line crossings before stopping1Q
KP = 0.008       # camera proportional gain (wall pixel area difference)
KD = 0.001      # camera derivative gain (damps oscillation from the wall pixel area difference)
KP_GYRO = 0.5   # gyro proportional gain (heading error in degrees)
KD_GYRO = 0.01  # gyro derivative gain (damps oscillation/overshoot from how fast the
                # heading error is changing), tune on track
KP_OBSTACLE = 0.4   # obstacle-avoidance proportional gain (target pixel error -> steering degrees)
KP_OBSTACLE_RED = 0.4  # RED-only override -- RED wasn't turning hard enough at the shared gain, tune on track
OBSTACLE_REACHED_PX = 20  # |cam_error| below this counts as "reached" the other-colour obstacle's pass point
OBSTACLE_REACHED_PY = 30  # |cam_error_y| below this required too -- x can align long before the robot is actually alongside the point
PARK_SQUARE_SIZE = 10  # small debug square drawn during IN_PARKING, tune on track
PARK_SQUARE_CENTER_Y = 75  # tune on track
STOP_AFTER_PARK_CLEARED = True  # TEMPORARY: hold once park_cleared instead of continuing into
                                 # the force turn -- flip to False to resume the rest of IN_PARKING
# Inner-wall tripwire: 3 points per turn direction, staggered diagonally toward the
# bottom-inner corner of the frame (closest to the robot, on the side it'll pass on
# after the locked-in turn). If obstacle-avoidance steering hugs that side tightly
# enough to put one of these points on black, that's a frame's warning before the
# robot actually clips the wall. CWR/CCL sets are mirror images of each other. Tune on track.
INNER_WALL_TRIPWIRE_CWR = [(300, 190), (305, 205), (310, 220)]  # near right edge, staggered down-right
INNER_WALL_TRIPWIRE_CCL = [(20, 190), (15, 205), (10, 220)]     # near left edge, mirror of CWR
INNER_WALL_SOFT_KP_SCALE = 0.4  # damps KP/KP_GYRO during a tripwire fallback -- soft peel-off, not a sharp correction

state = State.WALL_FOLLOW # authoritative: every branch below dispatches on this. Starts here so the
                            # out-parking manoeuvre runs before anything else; nothing ever sets state
                            # back to OUT_PARKING once it leaves, so it's guaranteed one-time.
stopping = False    # true once the stop sequence has started -- independent of `state`, which
                    # gets reassigned every frame by the obstacle-detection branch and would
                    # otherwise reset stop_time on every iteration
reversing_time = None  # timestamp REVERSING was entered
out_parking_start = None  # timestamp the OUT_PARKING manoeuvre began; None until the first OUT_PARKING frame
out_parking_steer = None  # locked-in max-steer value (opposite the closer wall) for the OUT_PARKING manoeuvre
out_parking_obs_clear_start = None  # timestamp the matching obstacle first read as gone from view;
                                     # None while it's still visible or before the min turn duration is met
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

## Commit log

2026-07-02 Open Challenge working code - vision and imu aided
2026-07-06 added a obstacle challenge file and modified the openchallenge_v2.py file to include the new colour ranges for the obstacle challenge. Made frames take lists of colours instead of a full colour.
2026-07-08 Refactor Frame class for better colour handling
    Refactor Frame class to improve colour range handling and contour detection.
2026-07-08 Refactor Frame class to support colour groups
2026-07-08 added pico code
2026-07-08 Add speed tracking and update frame dimensions
2026-07-09 made a second obstacle challenge file to test new wall-following algorithm that blends gyro and camera steering inputs. Added a new function navigate_wall() that takes in gyro heading, desired headin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
2026-07-10 Added reversing feature to second version of obstacle challenge, improved logic to not rewrite avoiding time each frame
2026-07-10 Fixed logic for detecting turn-colour lines in the open challenge. Now, the program will only look for a new turn-colour line if the robot is not currently in a "just turned" cooldown state. This pre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
    [obstaclechallenge.py]
2026-07-10 Refactor obstacle avoidance with state machine logic
    Refactor obstacle avoidance logic to implement a state machine for improved navigation and obstacle handling. Introduce new parameters and adjust steering calculations for better responsiveness.
2026-07-10 Changes to implmement and join together with the pico
2026-07-28 Fixed obstacle challnege so works better and smoother, added parking logic but vey basic for now
    [main.py, obstaclechallenge.py, test robot_controller_code.py]
2026-08-07 finished addding some corrections to open challenge and it mostly working. >>Still need to fix some minor issues
    [obstaclechallenge3.py]
2026-08-21 modified parking code and added TOF sensor code
2026-08-24 changed clamping values to accomadate new ackerman
2026-08-28 changed code to fix some turning scenarios
    [obstaclechallenge.py, obstaclechallenge3.py]
2026-08-31 Rework turning/obstacle-avoidance state handling in obstaclechallenge3
    Add POST_OBSTACLE_TURN as a dedicated gyro-only-steer phase after a turn
    fires from behind a matching-colour obstacle, add clear-delay hysteresis
    before leaving AVOIDING_OBSTACLE/TURNING's matching-obstacle wait, wire up
    the previously-dead OBSTACLE_REACHED_PX/PY thresholds so getting close to
    an obstacle's pass point counts as avoided even before it leaves frame,
    remove the old turn-timeout fallback, and retune speed/colour-range
    constants from track testing.
    [obstaclechallenge.py, obstaclechallenge3.py]
2026-09-01 Add encoder test script for Raspberry Pi motor control
    This script tests the motor and encoder setup on a Raspberry Pi using GPIO pins. It counts encoder pulses and controls motor direction and speed.
2026-09-01 Added encoder code
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2026-09-03 Rename Camera Mount Base.png to Battery Holder.png
2026-09-03 Rename Differential Connector.png to Differential to Axle Connector.png
2026-09-03 Add files via upload
    Adding 3D Circuit Schematic picture
2026-09-03 Add files via upload
    Adding Circuit Diagram picture
2026-09-04 Add files via upload
    Testing the motor encoder for parking control
2026-09-04 Enhance readme with schematic images
    Added a table with images for electronics schematics and connections.
2026-09-05 Expand README with team and project details
    Added detailed information about the team, project objectives, robot design, and iterations of the chassis development. Included sections for videos, images, and preliminary work insights.
2026-09-05 Revise team images and motor selection details
    Updated team pictures and added new motor specifications.
2026-09-05 Update README with motor specs and microcontroller details
    Added detailed specifications and images for motors, steering, and microcontroller selection. Updated sections on drive system and power architecture.
2026-09-06 Update README with images and component details
    Added images and updated descriptions for various components including motors, sensors, and microcontrollers. Improved clarity on the selection process for components used in the robot design.
2026-09-06 Insert summary video link in README
    Added a link to the summary video in the README.
2026-09-06 Enhance README with component details and diagrams
    Added detailed descriptions of the robot's components, including the chassis, motor fit, sensor comparisons, and final circuit architecture. Updated tables and images to enhance clarity and provide v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
2026-09-06 Add files via upload
    LEGO Wheels image added
2026-09-06 Update README with battery, servo, chassis, and power details
    Added detailed specifications and comparisons for the 12V Li-ion battery pack, steering servos, chassis material, and wheels. Included power system architecture and power budget calculations.
2026-09-06 Revise README with power architecture and software details
    Added sections on power system architecture, software logic, and reproducibility. Updated existing content for clarity and organization.
2026-09-06 Insert robot images in README
    Added a table with a team picture of the robot.
2026-09-06 Add files via upload
    Power Distribution Added
2026-09-06 Add files via upload
    Added Power Distribution
2026-09-06 Refactor README to streamline content and add details
    Removed redundant section on power consumption and runtime. Added details about obstacle avoidance logic and parking states.
2026-09-06 Revise specifications and remove IMU comparison
    Updated specifications for speed, current, and torque. Removed comparison table and final decision section regarding IMU selection.
2026-09-06 Revise obstacle detection and steering algorithm details
    Updated the explanation of the obstacle detection and steering algorithm to reflect changes in the approach for calculating target points and handling black pixel detection.
2026-09-06 Enhance README with project overview and videos
    Added an overview of the autonomous robot project, including objectives, development stages, and links to videos.
2026-09-06 Clean up README by removing flowchart table
    Removed redundant flowchart table from the README.
2026-09-06 Clarify description of CAD and wiring files
2026-09-06 Added STL files for the chassis base and other components, modified obstacle challenge code, and updated readme. Renamed some files for better organization.
    [Axle Connector 1.stl, Axle Connector 2.stl, Axle Connector 3.stl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]
2026-09-07 Add step-by-step assembly guide for robot
    Added a step-by-step assembly guide for the robot, detailing the assembly process from printing the chassis to bench testing before full track runs.
2026-09-07 Revise assembly guide and clarify sensor positions
    Updated assembly instructions and added important notes.
2026-09-07 Modified code to include encoder motor code
2026-09-09 added logic to listen to button press from the Pico
2026-09-09 To start program from the button press event on the Pico
